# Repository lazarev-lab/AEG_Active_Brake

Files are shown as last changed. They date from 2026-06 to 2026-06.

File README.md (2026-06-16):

# ⚡ AEG Active Brake & Electronic Trigger (MOSFET)




A compact high-performance MOSFET module for Airsoft Electric Guns (AEGs).

The design replaces traditional mechanical trigger contacts with an electronic switching system based on a half-bridge MOSFET driver, improving trigger response, reducing contact wear, and providing active motor braking to minimize overspin.

---

## ✨ Features

### ⚡ Electronic Trigger Switching

Mechanical trigger contacts carry only a low-current control signal while all motor current flows through dedicated power MOSFETs.

**Benefits:**

* Faster trigger response
* No contact arcing
* Increased trigger lifespan
* Lower electrical losses

---

### 🛑 Active Braking

Upon trigger release, the half-bridge actively drives the motor terminals toward the supply rail, rapidly dissipating the motor's rotational energy.

This significantly reduces gearbox overspin and helps prevent unintended double-shots, especially in high-speed builds.

---

### 🔒 Hardware Shoot-Through Protection

The design uses the `LM5106MM` half-bridge gate driver with a fixed **600 ns dead time**.

This hardware-enforced delay guarantees that the high-side and low-side MOSFETs cannot switch simultaneously.

**Benefits:**

* Prevents shoot-through currents
* Protects MOSFETs from failure
* Improves overall reliability

---

### 🛡️ Transient Protection

The circuit includes dedicated protection against voltage spikes generated by the motor.

| Component | Function |
| --- | --- |
| `SMBJ18A` | Clamps supply voltage transients during switching and braking |
| `SS34` | Provides an additional low-loss current path and suppresses inductive transients |

---

### 📶 Noise-Resistant Trigger Input

The trigger input uses an active-low configuration with a pull-up resistor.

This helps prevent accidental firing caused by:

* Electrostatic discharge (ESD)
* Electromagnetic interference (EMI)
* Floating trigger contacts

---

## ⚙️ Operating Principle

The trigger controls the `HB` input of the `LM5106MM`.

### Trigger Pressed

* `HB = LOW`
* High-side MOSFET OFF
* Low-side MOSFET ON
* Motor energized

### Trigger Released

* `HB = HIGH`
* High-side MOSFET ON
* Low-side MOSFET OFF
* Active braking engaged

The gate driver automatically inserts a fixed 600 ns dead time during every switching transition.

---

## 📊 Technical Specifications

| Parameter | Value |
| --- | --- |
| Operating Voltage | 7.4 V – 14.8 V Li-Po (2S–4S) |
| Gate Driver | `LM5106MM` |
| Dead Time | 600 ns |
| Power MOSFETs | 2 × `GT007N04TL` |
| TVS Diode | `SMBJ18A` |
| Schottky Diode | `SS34` |
| Trigger Type | Dry Contact / Microswitch |
| Active Brake | Yes |

---

## 🔌 Wiring

| Pad | Connection |
| --- | --- |
| **+Bat** | Battery Positive (+)  |
| **-Bat** | Battery Negative (-)  |
| **+Motor**  | Motor Positive (+) |
| **-Motor**  | Motor Negative (-) |
| **Buton** | Trigger Contact |
| **Buton_2** | Trigger Contact (GND) |

### Trigger Wiring

The trigger simply shorts `Buton` to `Buton_2` when pressed.

---

## ⚠️ Important Notes

### Reverse Polarity

This design does **not** include reverse-polarity protection.

Connecting the battery backwards may permanently damage:

* TVS diode
* Gate driver
* MOSFETs

Always verify wiring before connecting a battery.

### Recommended Batteries

* 2S Li-Po (7.4 V)
* 3S Li-Po (11.1 V)
* 4S Li-Po (14.8 V)

---

## 📂 Repository Structure

```text
.
├── *.kicad_pro     # KiCad project
├── *.kicad_sch     # Schematic
├── *.kicad_pcb     # PCB layout
└── .gitignore      # KiCad-specific ignore rules
```

---

## 🎯 Design Goals

* Fast trigger response
* Reliable active braking
* Compact PCB footprint
* High current capability
* Hardware shoot-through protection
* Low component count
* Easy installation in AEG gearboxes

---

## 📄 License

Released under the **MIT License**.

You are free to use, modify, manufacture, and distribute this design, including commercial use, provided that the original copyright notice and license text are retained.

See the `LICENSE` file for details.

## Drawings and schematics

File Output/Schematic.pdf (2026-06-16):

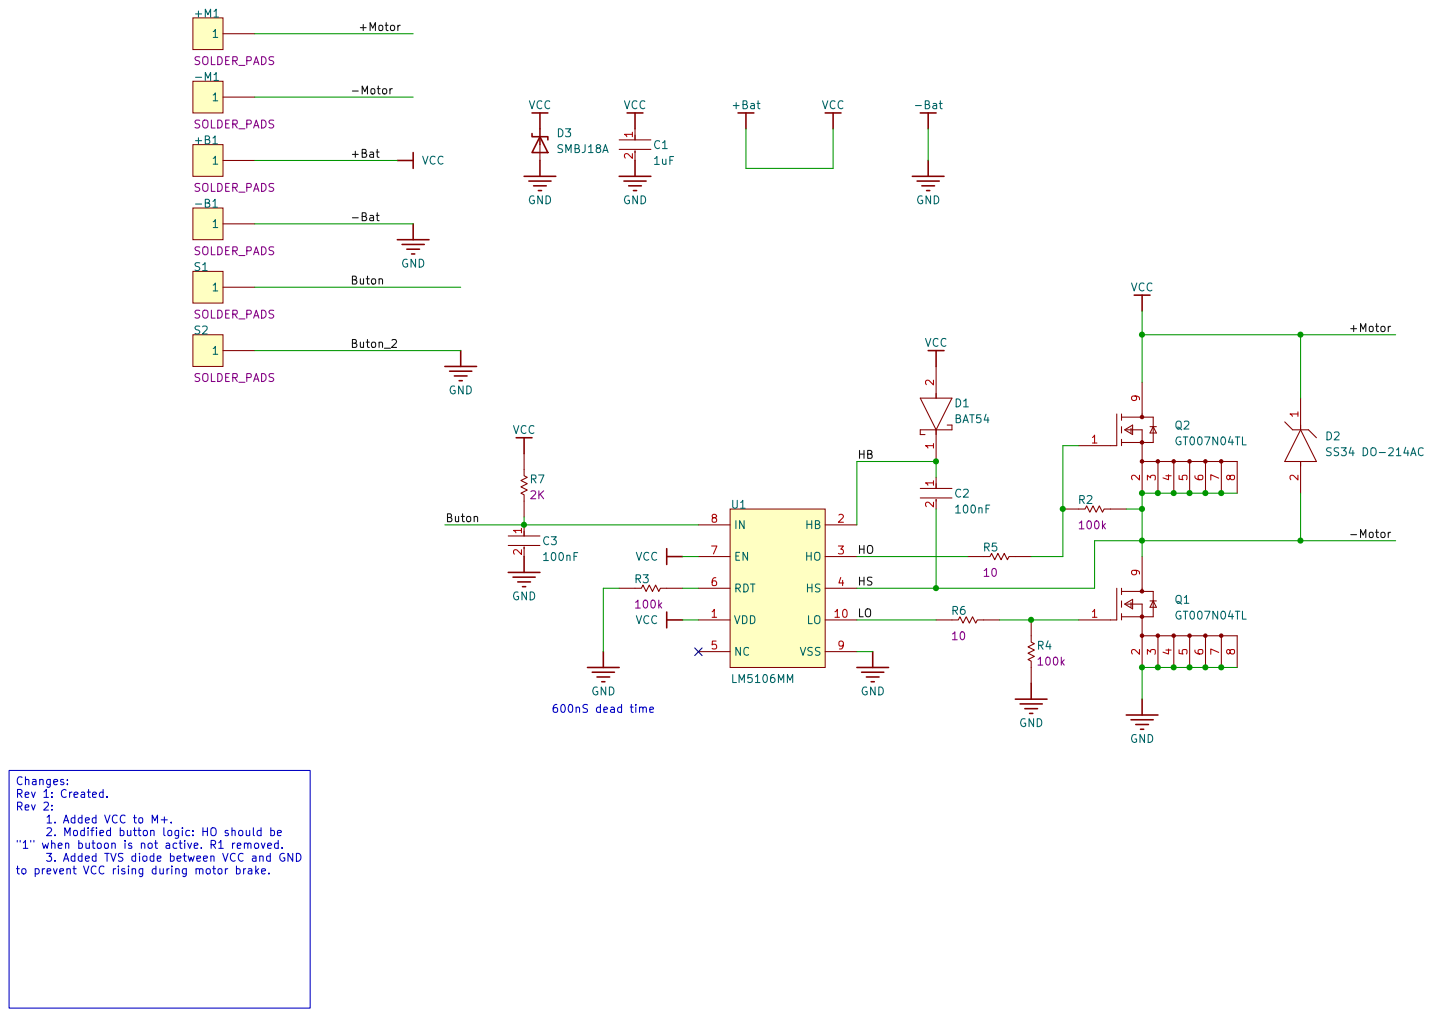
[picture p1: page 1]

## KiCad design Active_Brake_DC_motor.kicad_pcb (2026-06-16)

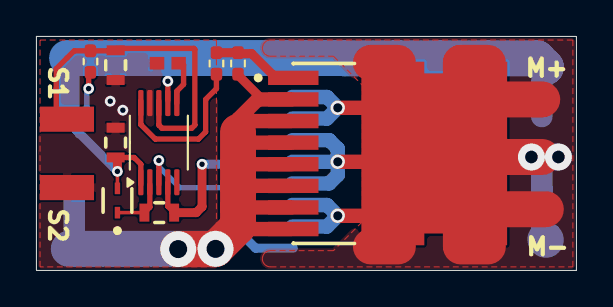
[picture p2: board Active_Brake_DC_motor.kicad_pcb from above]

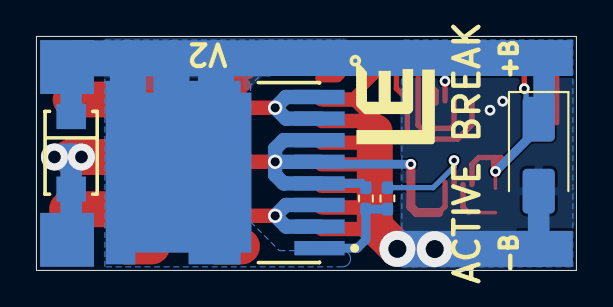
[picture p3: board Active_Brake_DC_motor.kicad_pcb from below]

Board: 2 copper layers, 30.0 x 13.0 mm, 21 parts (11 on the bottom side), 10 nets.

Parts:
+B: 3S_PADS_1WAY_1MM; PADS_1WAY_1MM
+M: 3S_PADS_1WAY_1MM; PADS_1WAY_1MM
-B: 3S_PADS_1WAY_1MM; PADS_1WAY_1MM
-M: 3S_PADS_1WAY_1MM; PADS_1WAY_1MM
C1: 1uF; FP-CGA3E-0_3-0_1-IPC_C
C2, C3: 100nF; FP-CGA3E-0_3-0_1-IPC_C
D1: BAT54; FP-SOD-523-MFG
D2: SS34 DO-214AC; FP-SMA-MFG
D3: SMBJ18A; D_SMA
Q1, Q2: GT007N04TL; FP-100CU-MFG
R2, R4: 100K; R_0402_1005Metric_Pad0.72x0.64mm_HandSolder
R3: 100K; 0402_RESC1005N
R5, R6: 10; R_0402_1005Metric_Pad0.72x0.64mm_HandSolder
R7: 2K; R_0402_1005Metric_Pad0.72x0.64mm_HandSolder
S, S1: 3S_PADS_1WAY_1MM; PADS_1WAY_1MM
U1: LM5106MM; VSSOP-10_3x3mm_P0.5mm

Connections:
+Bat: +B.1, +M.1, C1.1, D1.2 (A), D2.1 (K), D3.1 (A1), Q2.9 (D), R7.2, U1.1 (VDD), U1.7 (EN)
-Bat: -B.1, C1.2, C3.2, D3.2 (A2), Q1.2 (S), Q1.3 (S), Q1.4 (S), Q1.5 (S), Q1.6 (S), Q1.7 (S), Q1.8 (S), R3.1, R4.1, S.1, U1.9 (VSS)
-Motor: -M.1, C2.2, D2.2 (A), Q1.9 (D), Q2.2 (S), Q2.3 (S), Q2.4 (S), Q2.5 (S), Q2.6 (S), Q2.7 (S), Q2.8 (S), R2.2, U1.4 (HS)
/Buton: C3.1, R7.1, S1.1, U1.8 (IN)
/HB: C2.1, D1.1 (C), U1.2 (HB)
/HO: R5.2, U1.3 (HO)
/LO: R6.2, U1.10 (LO)
unnamed: Q1.1 (G), R4.2, R6.1
unnamed: Q2.1 (G), R2.1, R5.1
unnamed: R3.2, U1.6 (RDT)

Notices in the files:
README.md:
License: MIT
